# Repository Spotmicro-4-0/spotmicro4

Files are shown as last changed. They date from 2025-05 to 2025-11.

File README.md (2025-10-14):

# Spotmicro 4.0

All the 3D model SLT files are located here: [3D Models](3d-models/README.md)

## Setup Instructions

To get started with this repository, follow these steps:

1. **Use Visual Studio Code**: Clone the repository and open it in VS Code. Make sure to open the workspace file at the root of the repo (`spotmicroai.code-workspace`).

2. **Accept Recommended Plugins**: When prompted, accept the recommended extensions, which are primarily related to Python development.

3. **Create Environment**: Open the Command Palette (Ctrl+Shift+P) and select "Create Environment" to set up your Python environment.

4. **Install Dependencies**: Run the following command to install the development requirements:

   ```
   pip install -r requirements-dev.txt
   ```

- Configuring your controller
- [Joystick Documentation](docs/joystick.md)

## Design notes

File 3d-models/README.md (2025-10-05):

## 3D Models

Note: All parts were designed to be printed without the need for any support

### Assembly 1. Body
This is the central part of the bot, technically called the  tetrapod torso. It is basically the body of an animal without the 4 shoulders, limbs, head or buttock.

- It contains all the electronic components including the battery, except the LCD and the servos.
- Technically, the SBEC Cover and the Board Cover are optional. They can be skipped for now and printed at the end

|Assembly No|Assembly Name|Part|File Path|Count|Image||
|--|--|--|--|--|--|--|
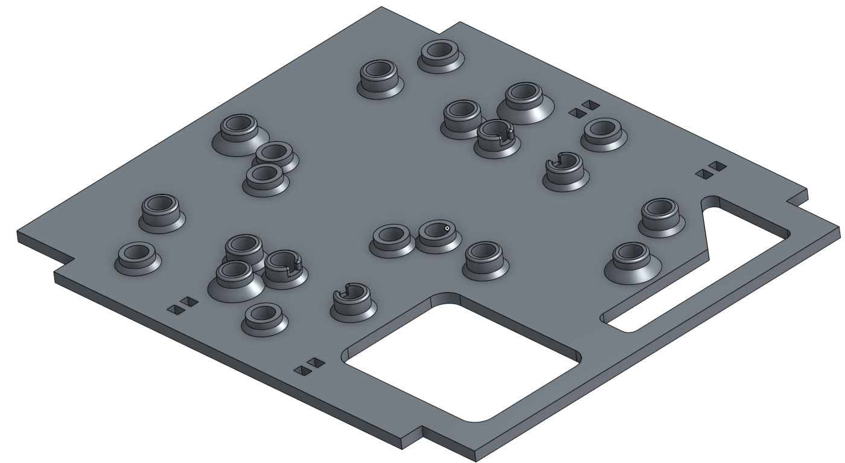
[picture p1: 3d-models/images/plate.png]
|1|Body|Plate|body/plate.stl|x1|||
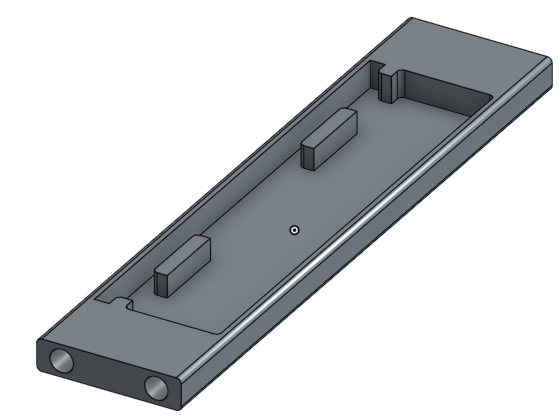
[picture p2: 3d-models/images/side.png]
|1|Body|Side|body/side.stl|x2|||
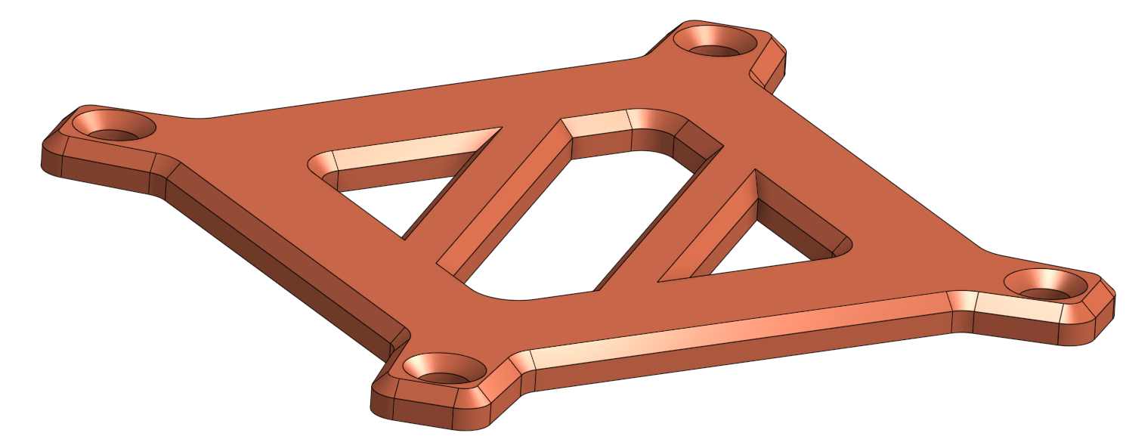
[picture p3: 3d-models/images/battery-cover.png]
|1|Body|Battery Cover|body/battery-cover.stl|x1||optional|
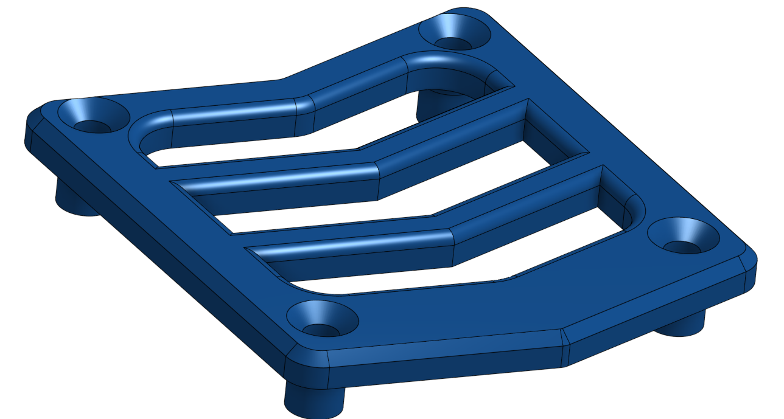
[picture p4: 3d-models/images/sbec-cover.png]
|1|Body|SBEC Cover|body/sbec-cover.stl|x1||optional|
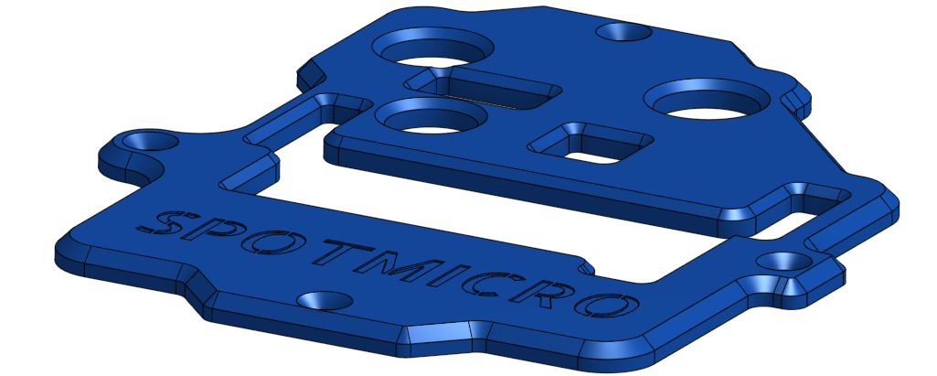
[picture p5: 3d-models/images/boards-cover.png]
|1|Body|Boards Cover|body/boards-cover.stl|x1||optional|

### Assembly 2. Front/Rear Shoulders

- This assembly is the shoulders cage that holds the Z-axis servos
- You will need two copies of this assembly
- Note that the limbs of the rear shoulders are reverse when compared to the front shoulders (left is right and right is left). More on that later

|Assembly No|Assembly Name|Part|File Path|Count|Image||
|--|--|--|--|--|--|--|
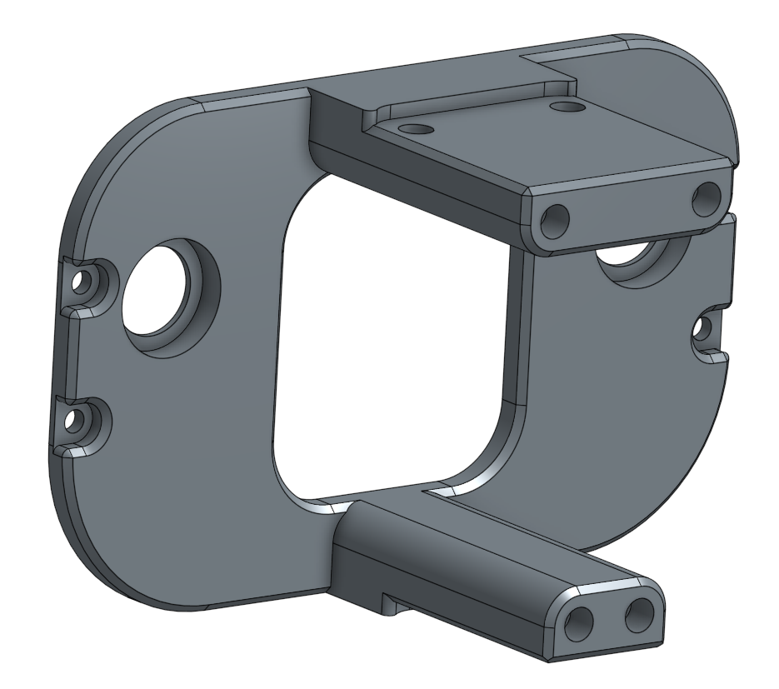
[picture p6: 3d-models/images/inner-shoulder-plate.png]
|2|Front/Rear Shoulders|Inner Shoulder Plate|shoulders/inner-plate/inner-shoulder-plate.stl|x2||
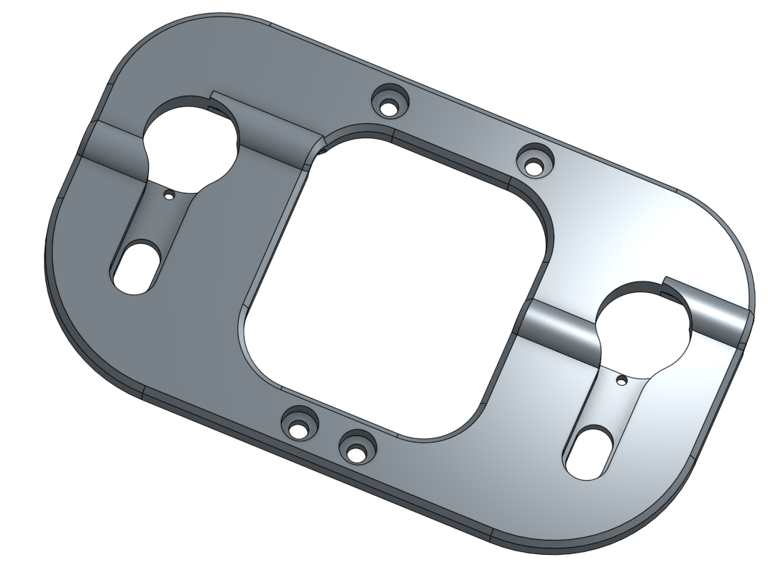
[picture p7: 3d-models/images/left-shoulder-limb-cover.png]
|2|Front/Rear Shoulders|Left Shoulder Limb Cover|shoulders/limb/left/left-shoulder-limb-cover.stl|x2||
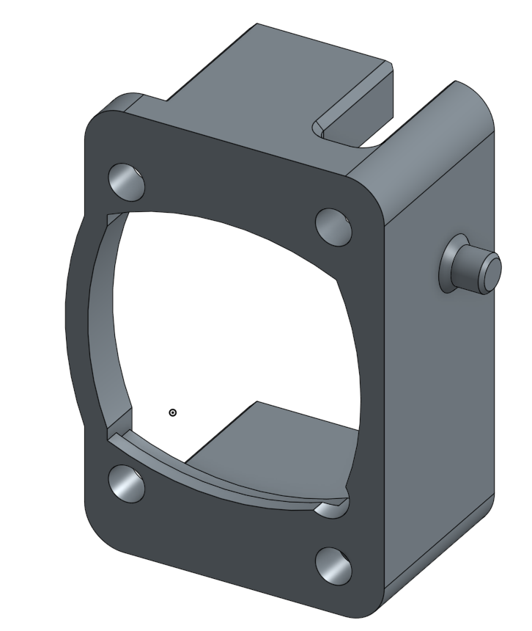
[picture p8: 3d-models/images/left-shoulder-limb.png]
|2|Front/Rear Shoulders|Left Shoulder Limb|shoulders/limb/left/left-shoulder-limb.stl|x2||
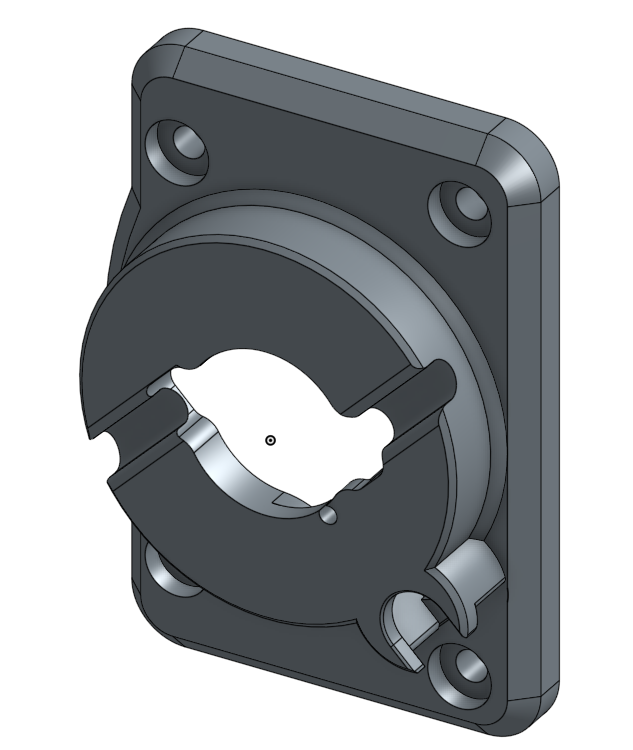
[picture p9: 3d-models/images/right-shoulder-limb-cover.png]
|2|Front/Rear Shoulders|Right Shoulder Limb Cover|shoulders/limb/right/right-shoulder-limb-cover.stl|x2||
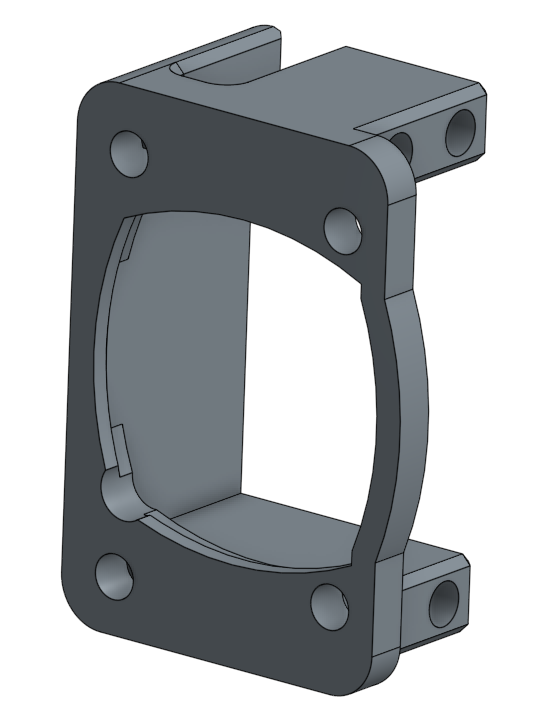
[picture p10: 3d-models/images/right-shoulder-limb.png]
|2|Front/Rear Shoulders|Right Shoulder Limb|shoulders/limb/right/right-shoulder-limb.stl|x2||
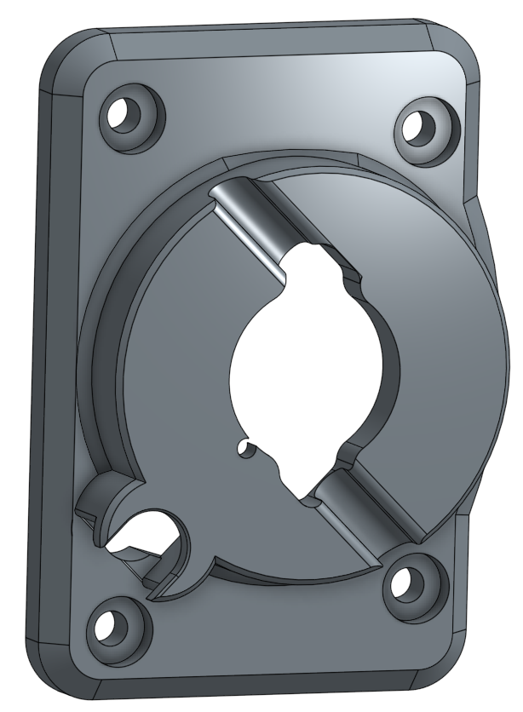
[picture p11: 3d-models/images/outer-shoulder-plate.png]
|2|Front/Rear Shoulders|Outer Shoulder Plate|shoulders/outer-plate/outer-shoulder-plate.stl|x2||

### Assembly 3. Left Leg
|Assembly No|Assembly Name|Part|File Path|Count|Image||
|--|--|--|--|--|--|--|
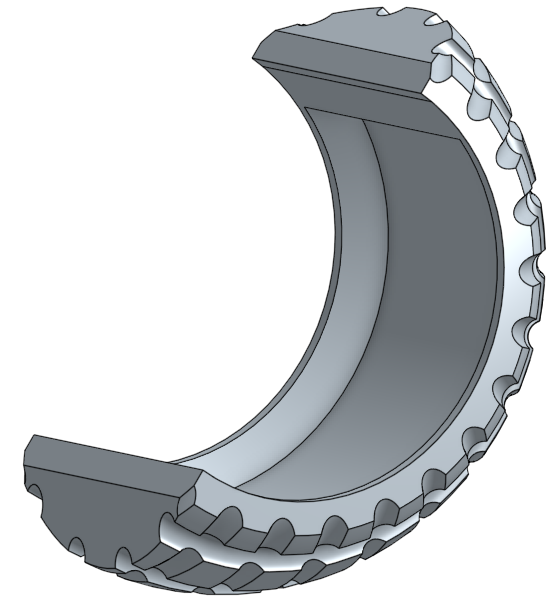
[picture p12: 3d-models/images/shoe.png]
|3|Left Leg|Shoe|legs/shoe.stl|x2||
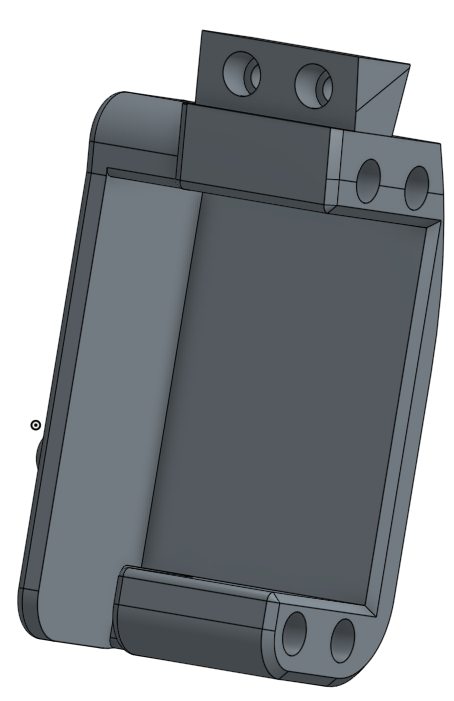
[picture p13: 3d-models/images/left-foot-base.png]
|3|Left Leg|Left Foot Base|legs/left/foot/left-foot-base.stl|x2||
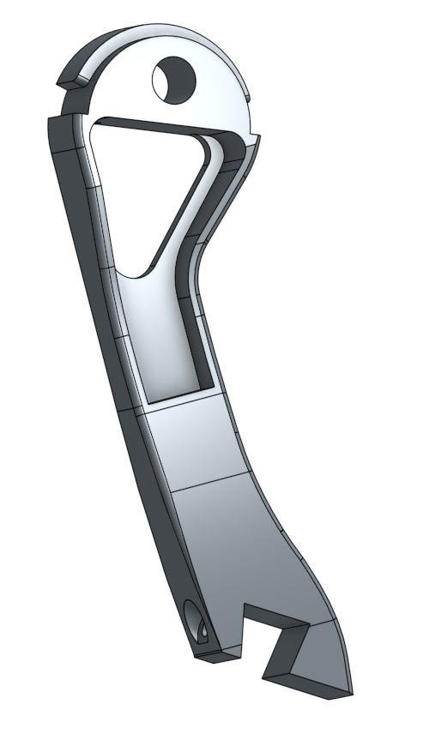
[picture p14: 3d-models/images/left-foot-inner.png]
|3|Left Leg|Left Foot Inner|legs/left/foot/left-foot-inner.stl|x2||
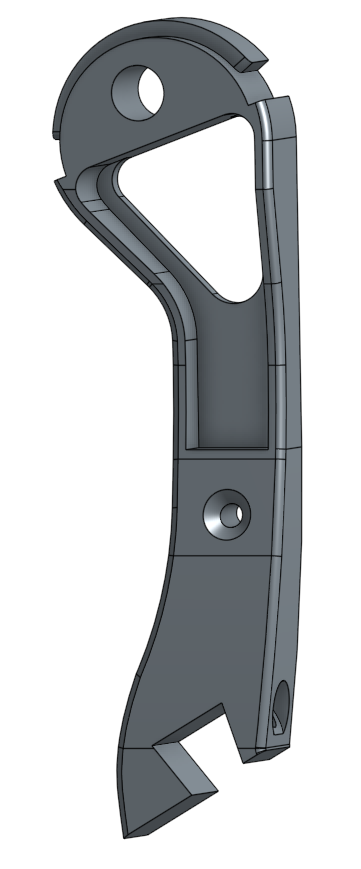
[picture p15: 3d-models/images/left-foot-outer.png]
|3|Left Leg|Left Foot Outer|legs/left/foot/left-foot-outer.stl|x2||
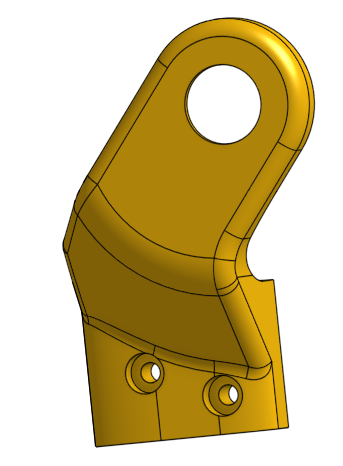
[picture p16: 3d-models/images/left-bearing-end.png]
|3|Left Leg|Bearing End|legs/left/leg/bearing-end.stl|x2||
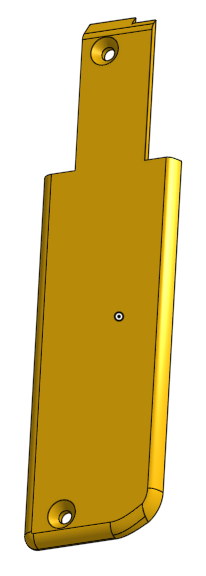
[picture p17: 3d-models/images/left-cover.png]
|3|Left Leg|Cover|legs/left/leg/cover.stl|x2||
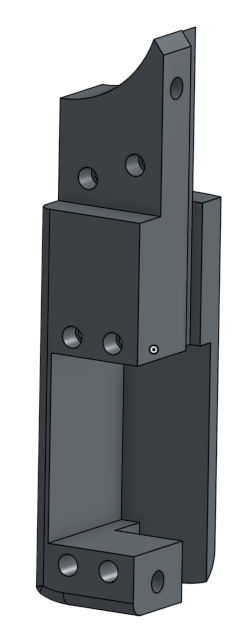
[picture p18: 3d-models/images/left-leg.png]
|3|Left Leg|Left Leg|legs/left/leg/left-leg.stl|x2||
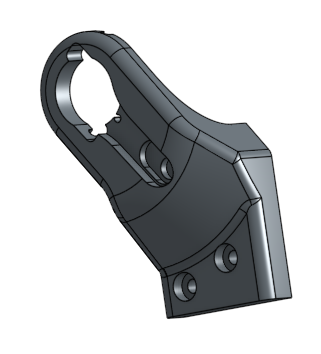
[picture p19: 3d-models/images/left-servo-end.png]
|3|Left Leg|Servo End|legs/left/leg/servo-end.stl|x2||

### Assembly 4. Right Leg
|Assembly No|Assembly Name|Part|File Path|Count|Image||
|--|--|--|--|--|--|--|
|4|Right Leg|Shoe|legs/shoe.stl|x2||
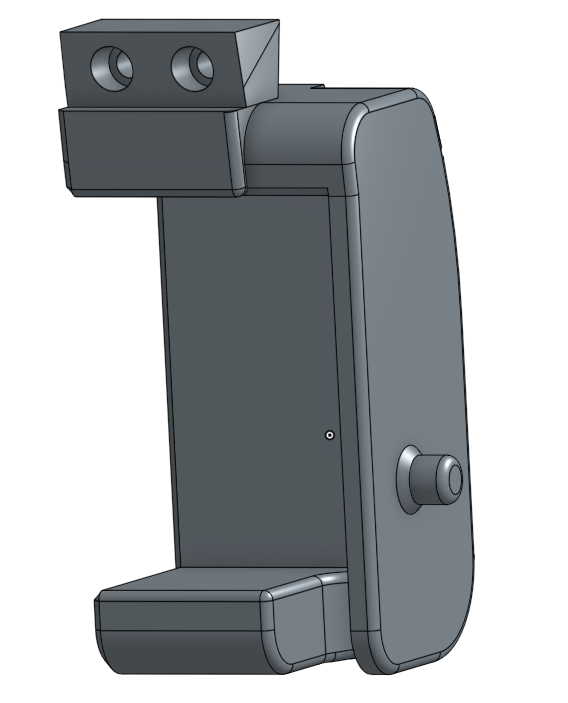
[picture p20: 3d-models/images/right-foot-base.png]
|4|Right Leg|Right Foot Base|legs/right/foot/right-foot-base.stl|x2||
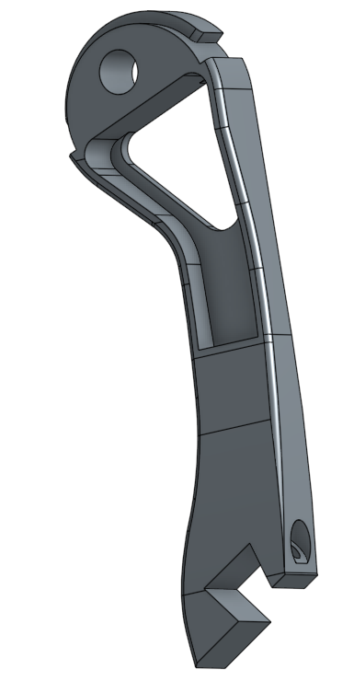
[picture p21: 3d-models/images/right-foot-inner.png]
|4|Right Leg|Right Foot Inner|legs/right/foot/right-foot-inner.stl|x2||
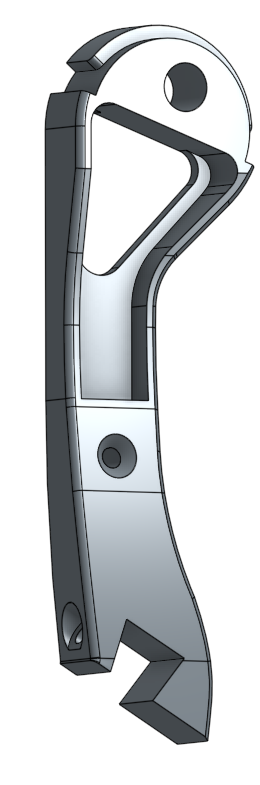
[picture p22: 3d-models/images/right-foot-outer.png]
|4|Right Leg|Right Foot Outer|legs/right/foot/right-foot-outer.stl|x2||
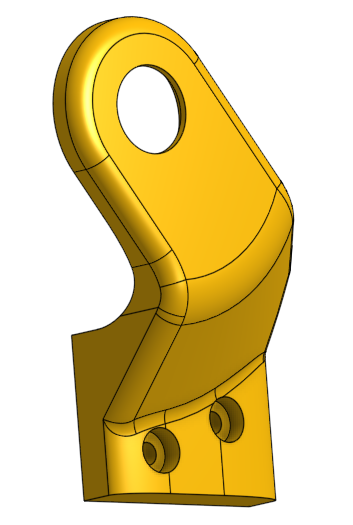
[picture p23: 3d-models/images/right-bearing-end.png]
|4|Right Leg|Bearing End|legs/right/leg/bearing-end.stl|x2||
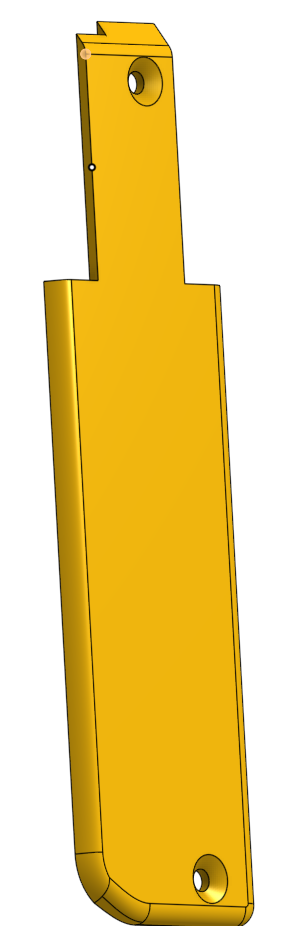
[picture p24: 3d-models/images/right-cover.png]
|4|Right Leg|Cover|legs/right/leg/cover.stl|x2||
|4|Right Leg|Right Leg|legs/right/leg/right-leg.stl|x2||
|4|Right Leg|Servo End|legs/right/leg/servo-end.stl|x2||

### Assembly 5. Top & Bottom Covers
Two very similar parts that wrap the body (the previous assembly). One cover goes on the top and the other on the bottom.

- The top cover has two openings, one for a power switch and another for accessing the battery charging connector
- The bottom cover has two optional parts that I call "offsets". They maybe needed if extra room is desired.

|Assembly No|Assembly Name|Part|File Path|Count|Image||
|--|--|--|--|--|--|--|
|5|Top/Bottom Covers|Bottom Panel|bottom/bottom-panel.stl|x1||
|5|Top/Bottom Covers|Edge Panel Connector|bottom/edge-panel-connector.stl|x4||
|5|Top/Bottom Covers|Left Side Panel|bottom/left-side-panel.stl|x2||
|5|Top/Bottom Covers|Offset|bottom/offset.stl|x2||
|5|Top/Bottom Covers|Right Side Panel|bottom/right-side-panel.stl|x2||
|5|Top/Bottom Covers|Charging Cover|top/charging-cover.stl|x1||
|5|Top/Bottom Covers|Top Cover with Opening|top/top-cover-with-opening.stl|x1||

### Assembly 6. Head
|Assembly No|Assembly Name|Part|File Path|Count|Image||
|--|--|--|--|--|--|--|
|6|Head|Connector|head/connector.stl|x1||
|6|Head|Face|head/face.stl|x1||
|6|Head|Middle|head/middle.stl|x1||
|6|Head|Nose|head/nose.stl|x1||

### Assembly 7. Rear
|Assembly No|Assembly Name|Part|File Path|Count|Image||
|--|--|--|--|--|--|--|
|7|Rear|Rear Cover|rear/rear-cover.stl|x2||

### Assembly 8. Stand

- Technically, this assembly is optional, but it is very difficult to calibrate and test the robot without it

|Assembly No|Assembly Name|Part|File Path|Count|Image||
|--|--|--|--|--|--|--|
|8|Stand|Base|stand/base-x-2.stl|x2||
|8|Stand|Cross Beam|stand/cross-beam-x-2.stl|x2||
|8|Stand|Foot|stand/foot-x-4.stl|x4||
|8|Stand|Fork|stand/fork-x-2.stl|x2||
|8|Stand|Stem|stand/stem-x-2.stl|x2||

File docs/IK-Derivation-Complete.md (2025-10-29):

# Inverse Kinematics Derivation for SpotMicro 3-DOF Leg with Shoulder Offset

Pure first-principles derivation. All formulas derived from scratch using only geometry and mathematics.

---

## 1. System Setup

### Physical Configuration
We have a 3-DOF leg with:
- **Joint 1 (Shoulder/Coxa)**: Located at origin p₁
- **Joint 2 (Hip/Femur base)**: Located at offset from p₁
- **Joint 3 (Knee/Tibia base)**: Connected to joint 2 via femur (L₁)
- **End effector (Foot)**: Connected to joint 3 via tibia (L₂)

### Coordinate Frame
- **X**: Forward/backward (positive backward)
- **Y**: Vertical (positive downward)
- **Z**: Lateral (positive rightward)

Origin p₁ is at the shoulder joint.

### Rigid Parameters
- **L₁** = 110 mm (femur/upper leg)
- **L₂** = 130 mm (tibia/lower leg)
- **Offset at rest**: When shoulder is at neutral (ω = 0), hip p₂ is at fixed position (28.5, 58.5, -10) relative to p₁

### Joint Angles
- **ω (omega)**: Shoulder rotation angle. Describes hip p₂ position around X-axis
- **θ (theta)**: Hip joint angle. Describes femur orientation in the plane perpendicular to shoulder axis
- **φ (phi)**: Knee joint angle. Internal angle between femur and tibia

---

## 2. Inverse Kinematics Derivation

### Problem Statement
Given a target foot position **t** = (X, Y, Z), find the joint angles (ω, θ, φ).

### Step 1: Derive ω (Shoulder Abduction/Adduction)

#### Physical Setup
The shoulder joint rotates around the X-axis. The hip joint p₂ is located at an offset from p₁. When the shoulder rotates by angle ω, the offset vector rotates in the YZ plane:

**At ω = 0°:**
$$p_2 = (x_{off}, y_{off}, z_{off}) = (28.5, 58.5, -10)$$

**After rotation by ω around X-axis:**
$$p_{2y} = y_{off}\cos(ω) - z_{off}\sin(ω)$$
$$p_{2z} = y_{off}\sin(ω) + z_{off}\cos(ω)$$

#### Deriving the Constraint
The key constraint is that the foot's Z-coordinate must equal the rotated offset's Z-component:
$$Z = y_{off}\sin(ω) + z_{off}\cos(ω)$$

#### Rewriting with Trigonometric Identity
We can rewrite the right-hand side using the sum formula:
$$Z = \sqrt{y_{off}^2 + z_{off}^2} \left[\frac{y_{off}}{\sqrt{y_{off}^2 + z_{off}^2}}\sin(ω) + \frac{z_{off}}{\sqrt{y_{off}^2 + z_{off}^2}}\cos(ω)\right]$$

Let $\sin(\delta) = \frac{z_{off}}{R}$ and $\cos(\delta) = \frac{y_{off}}{R}$:
$$Z = R[\cos(\delta)\sin(ω) + \sin(\delta)\cos(ω)]$$
$$Z = R\sin(ω + \delta)$$

#### Solving for ω
$$\sin(ω + \delta) = \frac{Z}{R}$$
$$ω + \delta = \arcsin\left(\frac{Z}{R}\right)$$

**Therefore:**
$$\boxed{ω = \arcsin\left(\frac{Z}{R}\right) - \delta}$$

#### Reachability Constraint
$$|Z| \le R \quad \Rightarrow \quad |Z| \le 59.35 \text{ mm}$$

---

### Step 2: Compute p₂ (Hip Position After Shoulder Rotation)

Once ω is determined, the hip joint position is:

$$\boxed{p_{2x} = x_{off} = 28.5 \text{ mm}}$$

$$\boxed{p_{2y} = y_{off}\cos(ω) - z_{off}\sin(ω) = 58.5\cos(ω) + 10\sin(ω)}$$

$$\boxed{p_{2z} = Z}$$

(The Z-coordinate equals the target Z by construction.)

---

### Step 3: Reduce to 2D Planar Problem

#### Project to XY Plane
The leg's remaining two joints (hip and knee) operate in the XY plane. We compute the relative position of the target foot from the hip joint:

$$\boxed{\Delta x = X - p_{2x} = X - 28.5}$$

$$\boxed{\Delta y = Y - p_{2y}}$$

#### Hip-to-Foot Distance
$$\boxed{d = \sqrt{(\Delta x)^2 + (\Delta y)^2}}$$

#### Reachability Constraint (2D Triangle Inequality)
For the two-link chain (L₁ and L₂) to reach distance d:
$$|L_1 - L_2| \le d \le L_1 + L_2$$
$$20 \text{ mm} \le d \le 240 \text{ mm}$$

---

### Step 4: Solve φ (Knee Internal Angle)

#### Law of Cosines
The hip joint p₂, end of femur p₃, and foot target t form a triangle with known side lengths L₁, L₂, and d.

Using the law of cosines:
$$d^2 = L_1^2 + L_2^2 - 2L_1L_2\cos(φ)$$

#### Solving for φ
$$\cos(φ) = \frac{L_1^2 + L_2^2 - d^2}{2L_1L_2}$$

$$\boxed{φ = \arccos\left(\frac{L_1^2 + L_2^2 - d^2}{2L_1L_2}\right)}$$

#### Numerical Robustness
Clamp the arccos argument to [-1, 1] to prevent numerical errors:
$$\cos(φ) = \max(-1, \min(1, \cos(φ)))$$

#### Special Cases
- When $φ = 0°$ (π radians): leg is fully extended
- When $φ = 180°$ (0 radians): leg is fully folded back

---

### Step 5: Solve θ (Hip Pitch Angle)

#### Decomposition into Auxiliary Angles
The hip angle is decomposed into two angles that must be combined:

**Angle α**: Direction from hip p₂ to foot t in the XY plane
$$\boxed{\alpha = \arctan2(\Delta y, \Delta x)}$$

**Angle β**: Angle between the femur (L₁) and the line from hip to foot
Using the law of cosines on the same triangle:
$$L_2^2 = L_1^2 + d^2 - 2L_1 d\cos(β)$$

$$\cos(β) = \frac{L_1^2 + d^2 - L_2^2}{2L_1 d}$$

$$\boxed{\beta = \arccos\left(\frac{L_1^2 + d^2 - L_2^2}{2L_1 d}\right)}$$

#### Numerical Robustness
Clamp the arccos argument:
$$\cos(β) = \max(-1, \min(1, \cos(β)))$$

#### Hip Angle (Knee-Down Configuration)
The femur angle is oriented at angle α, and β is the angle between the femur and the hip-to-foot line. In the "knee-down" (typical) configuration:

$$\boxed{\theta = \alpha - \beta}$$

#### Alternative (Knee-Up Configuration)
For an inverted leg geometry:
$$\theta = \alpha + \beta$$

---

## 3. Complete Algorithm

### Input
Target foot position: $(X, Y, Z)$ in mm

### Output
Joint angles: $(ω, θ, φ)$ in radians

### Algorithm Steps

```
1. Compute shoulder angle:
   IF |Z| > R:
      RETURN ERROR: "Z out of reach"
   END IF
   ω = arcsin(Z/R) - δ

2. Compute hip position:
   p₂ₓ = xₒff
   p₂ᵧ = yₒff·cos(ω) - zₒff·sin(ω)

3. Project to 2D plane:
   Δx = X - p₂ₓ
   Δy = Y - p₂ᵧ
   d = √(Δx² + Δy²)

4. Check 2D reachability:
   IF d < |L₁ - L₂| OR d > L₁ + L₂:
      RETURN ERROR: "Target distance unreachable"
   END IF

5. Compute knee angle:
   cos(φ) = clamp((L₁² + L₂² - d²)/(2·L₁·L₂), -1, 1)
   φ = arccos(cos(φ))

6. Compute hip angle:
   α = atan2(Δy, Δx)
   cos(β) = clamp((L₁² + d² - L₂²)/(2·L₁·d), -1, 1)
   β = arccos(cos(β))
   θ = α - β  (knee-down) or α + β (knee-up)

7. RETURN (ω, θ, φ)
```

---

## 4. Numerical Implementation

### Constants
```
L₁ = 110 mm
L₂ = 130 mm
xₒff = 28.5 mm
yₒff = 58.5 mm
zₒff = -10 mm
R = 59.35 mm
δ ≈ -0.1693 rad
```

### Pseudo-code with Clamping

```python
def inverse_kinematics(X, Y, Z):
    # Step 1: Shoulder angle
    if abs(Z) > R:
        raise ValueError(f"Z={Z} unreachable (max: ±{R})")
    omega = asin(Z/R) - delta
    
    # Step 2: Hip position
    p2x = x_off
    p2y = y_off*cos(omega) - z_off*sin(omega)
    
    # Step 3: 2D projection
    dx = X - p2x
    dy = Y - p2y
    d = sqrt(dx² + dy²)
    
    # Step 4: Check reachability
    if d < abs(L1 - L2) or d > L1 + L2:
        raise ValueError(f"d={d} unreachable")
    
    # Step 5: Knee angle
    cos_phi = clamp((L1² + L2² - d²)/(2*L1*L2), -1, 1)
    phi = acos(cos_phi)
    
    # Step 6: Hip angle
    alpha = atan2(dy, dx)
    cos_beta = clamp((L1² + d² - L2²)/(2*L1*d), -1, 1)
    beta = acos(cos_beta)
    theta = alpha - beta
    
    return omega, theta, phi
```

---

## 5. Validation & Examples

### Example 1: Foot Straight Down
**Input**: X=28.5, Y=170, Z=0

Expected: ω ≈ δ (since arcsin(0) = 0)

**Calculation**:
- ω = arcsin(0) - (-0.1693) = 0.1693 rad ≈ 9.70°
- p₂y = 58.5·cos(0.1693) + 10·sin(0.1693) ≈ 58.36 mm
- d ≈ √(0² + (170-58.36)²) ≈ 111.64 mm

### Example 2: Foot Forward and Down
**Input**: X=60, Y=143, Z=50

Expected: ω > δ (positive Z rotates shoulder to the right)

**Calculation**:
- ω = arcsin(50/59.35) - (-0.1693) ≈ 1.017 rad ≈ 58.29°
- p₂y = 58.5·cos(1.017) + 10·sin(1.017) ≈ 38.47 mm
- d ≈ √((60-28.5)² + (143-38.47)²) ≈ 109.47 mm

---

## 6. Reachability Envelope

The workspace is bounded by:

1. **Z-reach** (shoulder abduction/adduction):
   $$-59.35 \text{ mm} \le Z \le 59.35 \text{ mm}$$

2. **XY-reach** (hip and knee in 2D plane):
   $$20 \text{ mm} \le d \le 240 \text{ mm}$$
   where $d = \sqrt{(X-28.5)^2 + (Y-p_{2y})^2}$

3. **Combined constraint**: The workspace is a 3D region bounded by these limits.

---

## 7. Notes on Implementation

- **Use radians** internally; convert to degrees for display if needed
- **Numerical robustness**: Always clamp arccos arguments to [-1, 1]
- **Branch selection**: The formulas assume the "knee-down" configuration; use $\theta = \alpha + \beta$ for alternative geometry
- **Error handling**: Check both Z-reach and 2D distance reachability before computing angles
- **Singularities**: φ approaches 0 or π at the boundaries of reach; behavior at singularities may cause numerical issues

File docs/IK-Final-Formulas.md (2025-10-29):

# SpotMicro Inverse Kinematics - Final Mathematical Formulas

**As implemented and tested - exact formulas without calibration fudging**

---

## System Parameters

```
L₁ = 110 mm    (femur length)
L₂ = 130 mm    (tibia length)
x_off = 28.55 mm    (X offset of hip from shoulder)
y_off = 10.5 mm     (Y offset of hip at natural position)
z_off = 58.49 mm    (Z offset of hip at natural position)
```

## Joint Angle Convention

- **ω = 90°**: Normal standing position (leg pointing straight down)
- **ω = 180°**: Leg pointing straight sideways
- **ω = 0°**: Leg pointing inward (adducted)
- **θ = 0°**: Femur pointing straight down
- **θ = 90°**: Femur pointing straight backward (along X-axis)
- **φ**: Internal knee angle between femur and tibia

---

## Mathematical Formulas

### Step 1: Solve ω (Shoulder Angle)

**Constraint equation:**
$$Z = -y_{off} \cdot \cos(ω) + z_{off} \cdot \sin(ω)$$

**Rewritten as:**
$$Z = R \cdot \sin(ω + φ)$$

where:
$$R = \sqrt{y_{off}^2 + z_{off}^2}$$
$$φ = \arctan2(-y_{off}, z_{off})$$

**Solution:**
$$ω = \arcsin\left(\frac{Z}{R}\right) - φ$$

**Reachability constraint:**
$$|Z| \leq R$$

### Step 2: Compute Hip Position p₂

$$p_{2x} = x_{off}$$
$$p_{2y} = y_{off} \cdot \sin(ω) + z_{off} \cdot \cos(ω)$$
$$p_{2z} = Z \quad \text{(by construction)}$$

### Step 3: Project to 2D Problem

$$\Delta x = X - p_{2x}$$
$$\Delta y = Y - p_{2y}$$
$$d = \sqrt{(\Delta x)^2 + (\Delta y)^2}$$

**Reachability constraint:**
$$|L_1 - L_2| \leq d \leq L_1 + L_2$$

### Step 4: Solve φ (Knee Angle)

**Law of cosines:**
$$\cos(φ) = \frac{L_1^2 + L_2^2 - d^2}{2L_1L_2}$$

**Solution:**
$$φ = \arccos\left(\text{clamp}\left(\frac{L_1^2 + L_2^2 - d^2}{2L_1L_2}, -1, 1\right)\right)$$

### Step 5: Solve θ (Hip Angle)

**Auxiliary angles:**
$$α = \arctan2(\Delta y, \Delta x)$$
$$β = \arccos\left(\text{clamp}\left(\frac{L_1^2 + d^2 - L_2^2}{2L_1d}, -1, 1\right)\right)$$

**Solution (as currently implemented):**
$$θ = \frac{π}{2} - α + β$$

---

## Summary Algorithm

```python
def inverse_kinematics(X, Y, Z):
    # Step 1: Shoulder angle
    R = sqrt(y_off² + z_off²)
    phi = atan2(-y_off, z_off)
    omega = asin(Z/R) - phi
    
    # Step 2: Hip position
    p2x = x_off
    p2y = y_off * sin(omega) + z_off * cos(omega)
    
    # Step 3: 2D projection
    dx = X - p2x
    dy = Y - p2y
    d = sqrt(dx² + dy²)
    
    # Step 4: Knee angle
    phi = acos(clamp((L1² + L2² - d²)/(2*L1*L2), -1, 1))
    
    # Step 5: Hip angle
    alpha = atan2(dy, dx)
    beta = acos(clamp((L1² + d² - L2²)/(2*L1*d), -1, 1))
    theta = π/2 - alpha + beta
    
    return (omega, theta, phi)
```

---

## Notes

- **The θ formula produces values ~6° lower than expected measurements**
- **The 0.105 radian (~6°) offset in the code is a calibration fudge, not a mathematical solution**
- **The underlying geometric relationship for θ may need reconsideration**
- **All other angles (ω and φ) match measurements accurately**

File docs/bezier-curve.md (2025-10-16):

# Bézier Curve Foot Trajectory Generator (SpotMicro4)

## Overview
This script replaces the discrete 6-point keyframe “box” walking cycle for a single foot with a **smooth Bézier curve** trajectory.  
Each keyframe defines a 3D coordinate `(X, Y, Z)` in millimeters:
- **X** → forward/backward  
- **Y** → up/down (vertical)  
- **Z** → inward/outward (toward/away from the robot center)

By interpolating these six positions using a Bézier curve, we generate a continuous, smooth path that the robot’s foot can follow during a walking step, reducing mechanical jerk and improving realism.

The Y-axis is plotted **vertically**, and inverted so that positive Y values correspond to **downward movement**, matching the robot’s coordinate convention.

---

## Script: `bezier.py`

```python
import numpy as np
import matplotlib.pyplot as plt
import math

# Your 6 keyframes (in mm)
points = np.array([
    [-60, 150, 40],
    [-60, 80, 40],
    [60, 80, 40],
    [60, 150, 40],
    [35, 150, 40],
    [-35, 150, 40],
])

def bezier_curve(points, num=200):
    n = len(points) - 1
    t = np.linspace(0, 1, num)
    curve = np.zeros((num, 3))
    for i in range(n + 1):
        binomial = math.comb(n, i)
        curve += (
            binomial * ((1 - t) ** (n - i)) * (t ** i)
        )[:, None] * points[i]
    return curve

curve = bezier_curve(points)

# Plot with Y as vertical and inverted
fig = plt.figure()
ax = fig.add_subplot(projection='3d')

# Swap Y/Z for visualization so Y is vertical
ax.plot(points[:, 0], points[:, 2], points[:, 1], 'ro--', label='Keyframes')
ax.plot(curve[:, 0], curve[:, 2], curve[:, 1], 'b-', label='Bezier Curve')

ax.set_xlabel('X (forward/backward)')
ax.set_ylabel('Z (outward/inward)')
ax.set_zlabel('Y (up/down)')
ax.invert_zaxis()  # invert Y axis (vertical)
ax.legend()
plt.tight_layout()
plt.savefig("bezier_curve.png", dpi=200)
print("Saved to bezier_curve.png with Y axis inverted (downward positive)")
```

## Output

Running the script:

```bash
python3 src/bezier.py
```

produces: `bezier_curve.png`

This PNG visualizes:

- The original 6 red keyframes connected by dashed lines
- The smooth blue Bézier curve interpolating the same spatial path
- The Y-axis plotted vertically and inverted to reflect the robot's coordinate frame.

Bezier Curve Visualization

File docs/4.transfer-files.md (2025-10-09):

- Enable i2c driver
sudo nano /boot/firmware/config.txt
dtparam=i2c_arm=on

- create a spotmicro folder
cd ~/spotmicroai || exit

- python3 -m venv venv --clear
- source venv/bin/activate

- install pip
curl https://bootstrap.pypa.io/get-pip.py | python
- install packages
sudo apt install python3-rpi.gpio

python3 -m pip install --upgrade pip setuptools jmespath throttle adafruit-circuitpython-motor adafruit-circuitpython-pca9685 inputs smbus RPi.GPIO pick

- copy files over to the rpi
- copy json

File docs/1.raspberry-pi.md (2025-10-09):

# Raspberry Pi Zero 2 W Setup Guide (Bookworm Lite)

This guide explains how to prepare a **microSD card** for your Raspberry Pi Zero 2 W using the **Raspberry Pi Imager**. It walks through selecting the correct image, configuring Wi-Fi, setting up credentials, and assigning a hostname.

---

## 1. Requirements

Before you begin, make sure you have:

* A **Raspberry Pi Zero 2 W** board
* A **microSD card** (8 GB minimum, 16 GB recommended)
* A **microSD card reader** for your computer
* A stable **Wi-Fi network**
* A computer running **Windows, macOS, or Linux**
* The latest **Raspberry Pi Imager** installed ([Download here](https://www.raspberrypi.com/software))

---

## 2. Launch Raspberry Pi Imager

1. Open the **Raspberry Pi Imager** application on your computer.
2. Click **"Choose Device"** and select **Raspberry Pi Zero 2 W**.

---

## 3. Choose the Operating System

1. Click **"Choose OS"**.
2. Navigate to:

   ```
   Raspberry Pi OS (other) → Raspberry Pi OS Lite (64-bit)
   ```

   This version (Bookworm Lite) is **command-line only** and ideal for robots or headless projects.

---

## 4. Select the Storage Device

1. Click **"Choose Storage"**.
2. Select your **microSD card** from the list. Make sure you choose the correct drive — this will erase all existing data.

---

## 5. Configure Advanced Settings

Click the small **gear icon ⚙️** or press **Ctrl + Shift + X** to open the **Advanced Options** menu.

Enable and configure the following:

### a. Set Hostname

```
spotmicroai
```

(You can choose another if desired, but `spotmicroai` is recommended.)

### b. Enable SSH

* Check **Enable SSH**
* Select **Use password authentication**

### c. Set Username and Password

Use simple credentials for first setup:

```
Username: pi
Password: raspberry
```

(You can change these later using the `passwd` command.)

### d. Configure Wi-Fi

Enter your Wi-Fi credentials:

```
SSID: <your_network_name>
Password: <your_network_password>
Country: US
```

Ensure the Wi-Fi name and password are typed exactly as they appear on your network.

### e. Set Locale Options

Optionally, adjust **Time Zone** and **Keyboard Layout** to match your region.

---

## 6. Save and Write the Image

1. Click **Save** to close the Advanced Options.
2. Click **Write** to begin flashing the SD card.
3. Wait for the process to complete — this may take a few minutes.
4. When finished, remove the SD card safely from your computer.

---

## 7. Boot the Raspberry Pi

1. Insert the flashed microSD card into the **Raspberry Pi Zero 2 W**.
2. Connect power via the **micro-USB port**.
3. Wait for it to boot (usually 30–60 seconds).

If configured correctly, your Pi will:

* Automatically connect to your Wi-Fi
* Be reachable via SSH at the hostname you set

You can verify connectivity by running from another computer on the same network:

```bash
ping spotmicroai.local
```

Or SSH into it directly:

```bash
ssh pi@spotmicroai.local
```

(Use the password you configured earlier.)

---

## 8. Optional: Verify System Details

Once connected, check:

```bash
hostnamectl
```

This confirms your hostname, OS version (Bookworm Lite), and architecture.

---

## 9. Next Steps

* Update packages: `sudo apt update && sudo apt upgrade -y`
* Install additional tools if needed (`git`, `python3`, `pip`, etc.)
* Begin deploying your robot or automation code.

Your Raspberry Pi Zero 2 W is now ready for headless operation.

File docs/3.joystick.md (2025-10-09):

# Game Controller Setup Guide for Raspberry Pi

This guide explains how to pair and test an **Xbox or PlayStation controller** wirelessly via Bluetooth on a Raspberry Pi.
It assumes you are using **Raspberry Pi OS Bookworm** or **Bullseye**.

---

## Prerequisites

Ensure your system is up to date. On most Bookworm installations, Bluetooth support is already included. The only extra package needed is `joystick` to use the testing tool.

```bash
sudo apt update
sudo apt upgrade -y
sudo apt install -y joystick
```

Verify that Bluetooth is active:

```bash
systemctl status bluetooth
```

If you see `active (running)`, you are ready.

---

## Supported Controllers

| Controller | Works via Bluetooth | Notes |
| --- | --- | --- |
| Xbox One S / Series X | Yes | Requires Bluetooth 4.0+; may need `xpadneo` driver for full rumble and battery support |
| PlayStation DualShock 4 | Yes | Fully supported by built-in Linux driver `hid-sony` |
| PlayStation DualSense (PS5) | Yes | Supported by `hid-playstation` driver in kernel 5.12+ |

---

## Pairing the Controller

### 1. Start Bluetooth services

```bash
sudo systemctl enable bluetooth
sudo systemctl start bluetooth
```

### 2. Enter the Bluetooth shell

```bash
bluetoothctl
```

Then run:

```text
power on
agent on
default-agent
scan on
```

---

### 3. Put the controller in pairing mode

* **Xbox controller:** Hold the **Pair** button (on top near the USB port) until the Xbox logo blinks rapidly.
* **PlayStation controller:** Hold **Share + PS** buttons together until the light bar flashes quickly.

---

### 4. Wait for detection

When the controller is found, you will see output like:

```
[NEW] Device DC:0C:2D:AB:1E:5A Xbox Wireless Controller
```

or

```
[NEW] Device 04:5D:4B:8A:BB:9E Wireless Controller
```

---

### 5. Pair and connect

Replace <MAC> with the detected Bluetooth address:

```text
pair <MAC>
trust <MAC>
connect <MAC>
```

Once connected, the controller light becomes solid.

---

### 6. Verify input device

Exit `bluetoothctl` and check:

```bash
ls /dev/input/
```

You should see something like:

```
js0
```

Test it:

```bash
jstest /dev/input/js0
```

Move the sticks or press buttons to confirm input is detected.

---

## Troubleshooting

### Controller not detected

Restart Bluetooth services:

```bash
sudo systemctl restart bluetooth
```

If still not listed, unpair and try again:

```bash
bluetoothctl
remove <MAC>
```

### Controller disconnects automatically

Controllers enter sleep mode when idle. Press the main button (Xbox logo or PS button) to reconnect.

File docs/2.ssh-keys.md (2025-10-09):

# Secure SSH Key Setup for Raspberry Pi

This guide explains how to configure passwordless SSH access to your Raspberry Pi using public and private key authentication. It applies to Raspberry Pi OS Bookworm (Lite or Desktop) and works from Linux, macOS, or Windows (including WSL or PowerShell).

---

## 1. Prerequisites

You should already have:

* Your Raspberry Pi powered on and connected to Wi-Fi or Ethernet
* SSH enabled on the Pi

  * If not, run `sudo raspi-config`, go to Interface Options > SSH > Enable
* The hostname or IP address of your Pi (for example, `spotmicroai.local`)

---

## 2. Check for Existing SSH Keys (on Your Computer)

Open a terminal on your local computer (not the Pi):

```bash
ls ~/.ssh
```

If you see files such as `id_rsa` and `id_rsa.pub` or `id_ed25519` and `id_ed25519.pub`, you already have a key pair and can skip to Step 4.

If not, continue.

---

## 3. Generate a New SSH Key Pair

Run the following command on your local computer:

```bash
ssh-keygen -t ed25519 -C "your_email@example.com"
```

Explanation:

* `-t ed25519` creates a modern, secure key type (recommended over RSA)
* `-C` adds an optional comment to help identify the key later

Press Enter to accept the default file location (`~/.ssh/id_ed25519`) and optionally set a passphrase for extra security.

---

## 4. Copy Your Public Key to the Raspberry Pi

Use one of the following methods.

### Option A: Using ssh-copy-id (recommended)

```bash
ssh-copy-id pi@spotmicroai.local
```

Replace `pi@spotmicroai.local` with your Pi's username and hostname or IP address. You will be asked for your Pi's password one last time. This command automatically adds your key to `~/.ssh/authorized_keys` on the Pi.

### Option B: Manual Copy

If `ssh-copy-id` is not available, you can copy the key manually:

1. Display your public key:

   ```bash
   cat ~/.ssh/id_ed25519.pub
   ```
2. Copy the output string.
3. On the Pi, connect via password SSH:

   ```bash
   ssh pi@spotmicroai.local
   ```
4. On the Pi, create or edit the file:

   ```bash
   mkdir -p ~/.ssh
   nano ~/.ssh/authorized_keys
   ```
5. Paste the public key into the file, save, and exit.
6. Set the correct permissions:

   ```bash
   chmod 700 ~/.ssh
   chmod 600 ~/.ssh/authorized_keys
   ```

---

## 5. Test the Connection

On your local computer, run:

```bash
ssh pi@spotmicroai.local
```

If setup was successful, you should connect without being asked for a password.

---

## 6. Troubleshooting

If you are still prompted for a password:

* Ensure SSH is enabled on the Pi: `sudo systemctl status ssh`
* Check that your key was copied correctly to `~/.ssh/authorized_keys`
* Verify file permissions are correct (as listed above)
* Make sure you are connecting as the same username for which the key was installed

---

## 7. Optional: Use a Custom Key Path

If your key is stored in a custom file, specify it with:

```bash
ssh -i ~/.ssh/custom_key pi@spotmicroai.local
```

You can also define this permanently in an SSH config file:

```bash
nano ~/.ssh/config
```

Example configuration:

```text
Host spotmicroai
    HostName spotmicroai.local
    User pi
    IdentityFile ~/.ssh/id_ed25519
```

Now you can simply connect using:

```bash
ssh spotmicroai
```

Your Raspberry Pi is now configured for secure, passwo

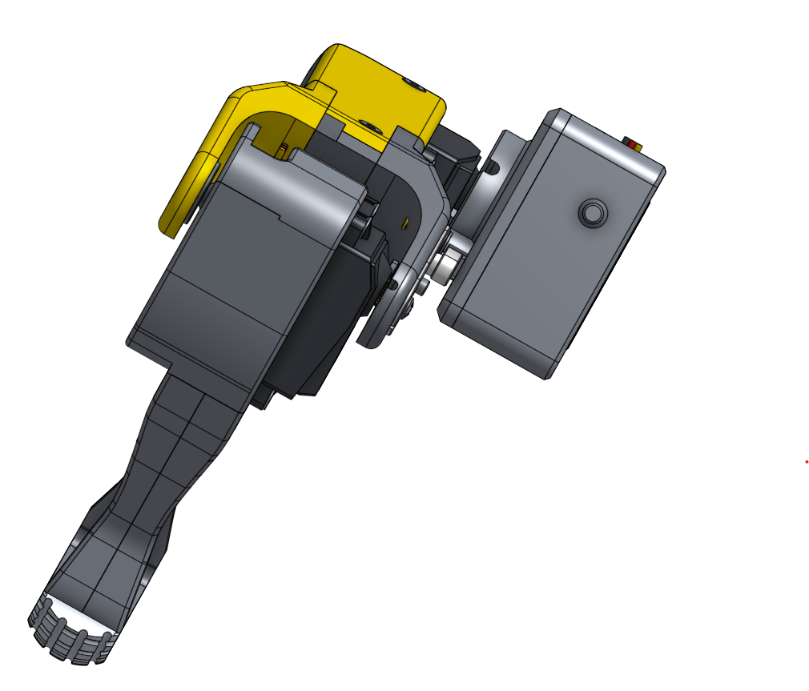
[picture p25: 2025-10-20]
docs/images/inverse-kinematics-rear.png

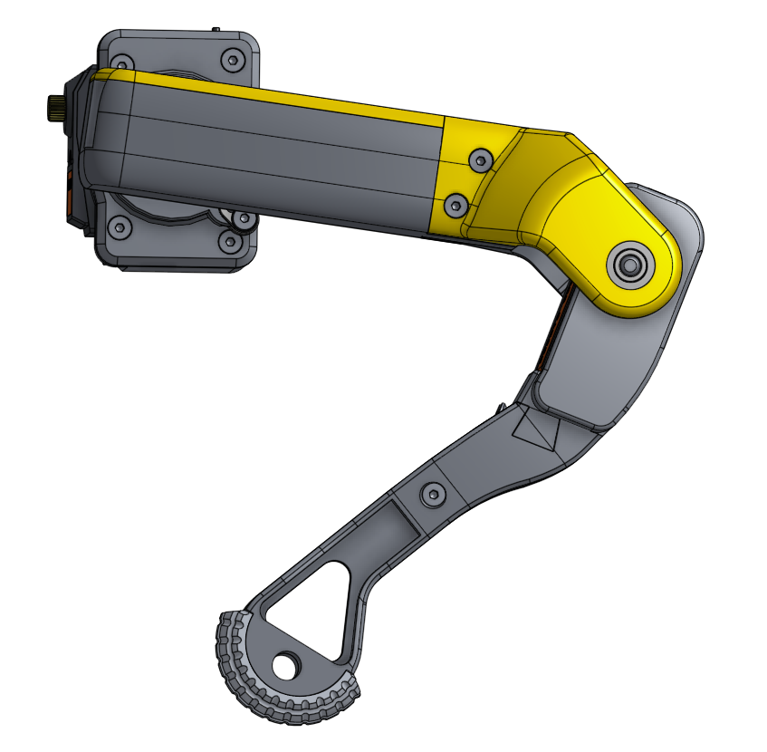
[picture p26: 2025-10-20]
docs/images/inverse-kinematics-side.png

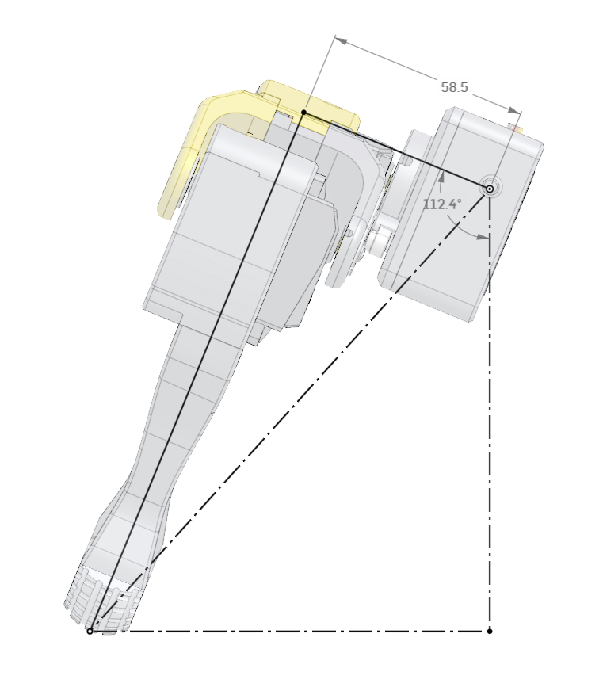
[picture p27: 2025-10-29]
docs/images/image.png

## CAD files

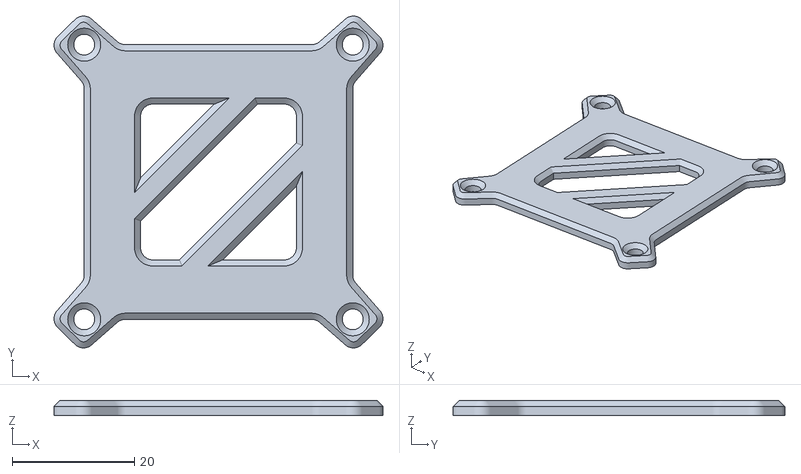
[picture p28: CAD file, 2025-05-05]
3d-models/body/battery-cover.stl
53.9 x 54.4 x 2.50

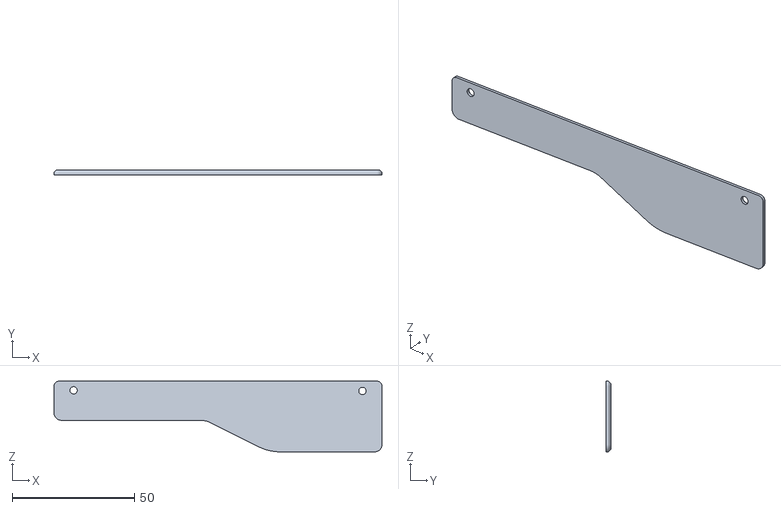
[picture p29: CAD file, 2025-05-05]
3d-models/bottom/right-side-panel.stl
134.0 x 2.00 x 28.9

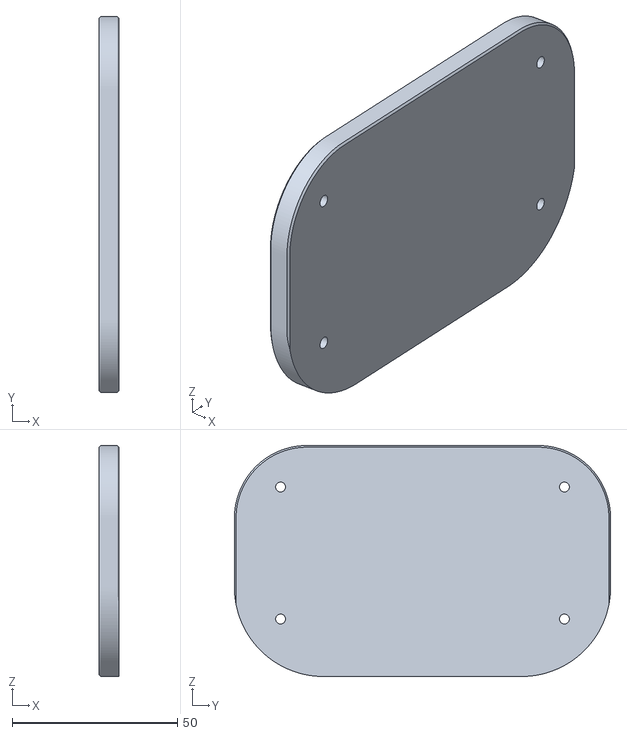
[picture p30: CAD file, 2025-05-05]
3d-models/head/middle.stl
6.00 x 114.0 x 70.0

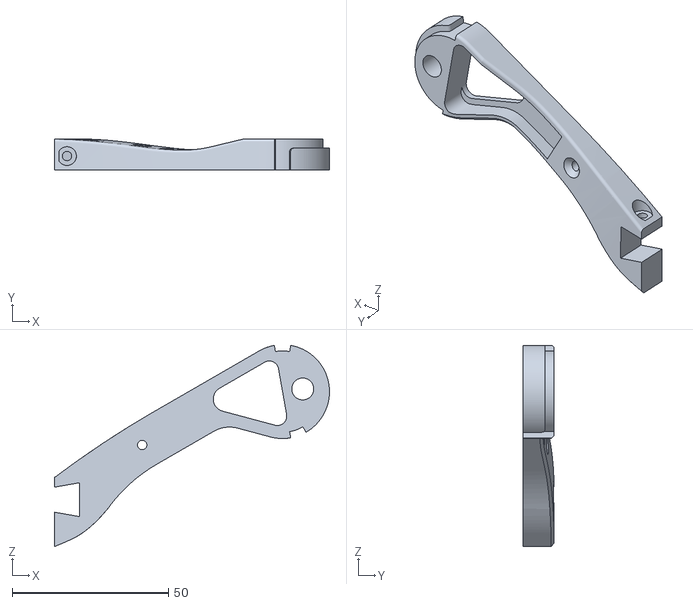
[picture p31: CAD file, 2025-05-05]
3d-models/legs/left/foot/left-foot-outer.stl
87.9 x 10.0 x 64.3

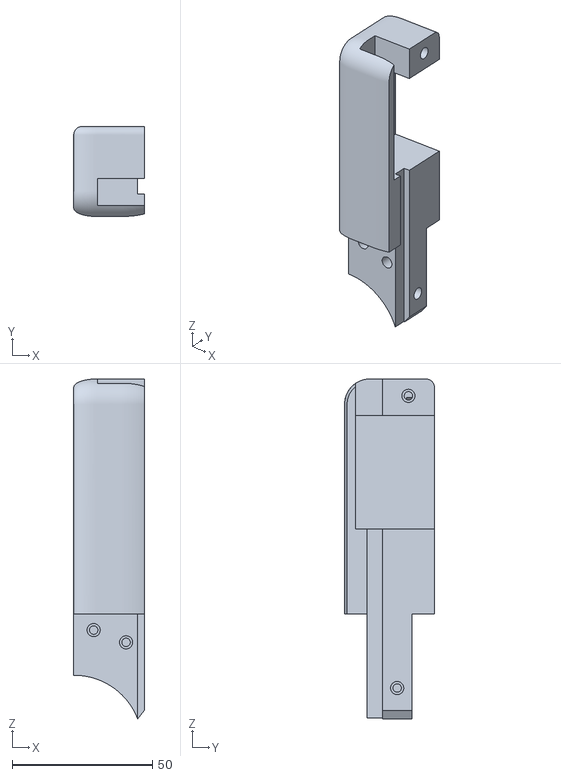
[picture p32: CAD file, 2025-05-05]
3d-models/legs/left/leg/left-leg.stl
25.2 x 32.1 x 121.3

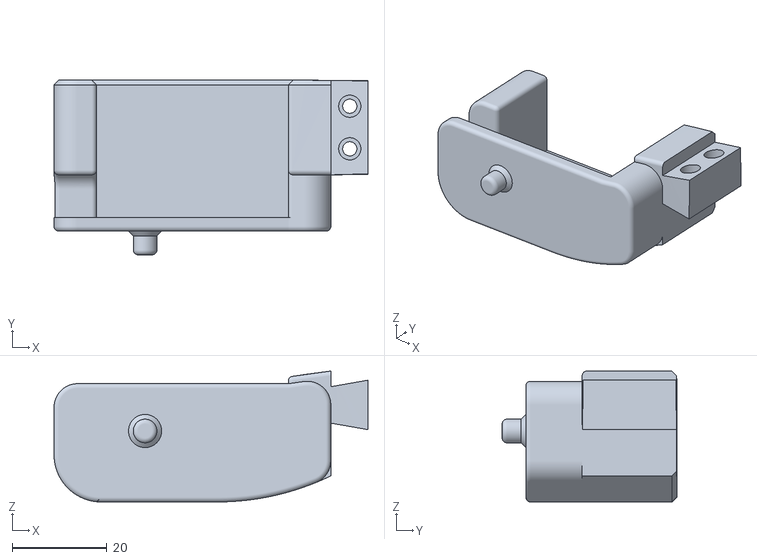
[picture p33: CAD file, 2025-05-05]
3d-models/legs/right/foot/right-foot-base.stl
66.4 x 36.9 x 27.7

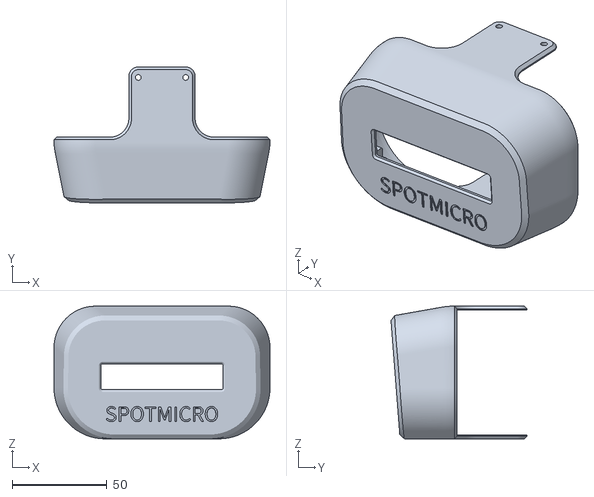
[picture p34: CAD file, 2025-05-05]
3d-models/rear/rear-cover.stl
114.0 x 71.8 x 70.0

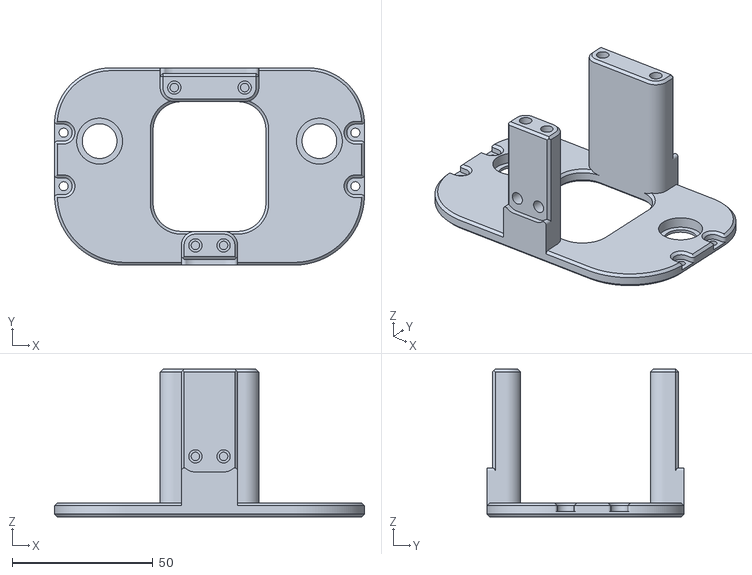
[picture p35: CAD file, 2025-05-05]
3d-models/shoulders/inner-plate/inner-shoulder-plate.stl
110.0 x 70.0 x 52.5

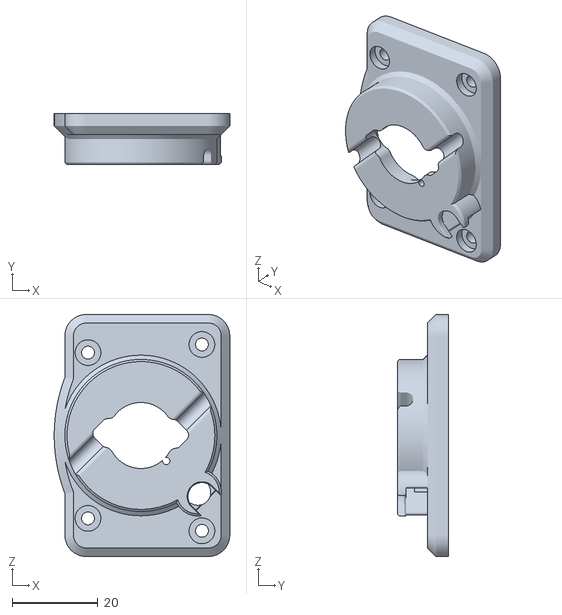
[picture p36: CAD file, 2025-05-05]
3d-models/shoulders/limb/left/left-shoulder-limb-cover.stl
41.0 x 12.0 x 56.5

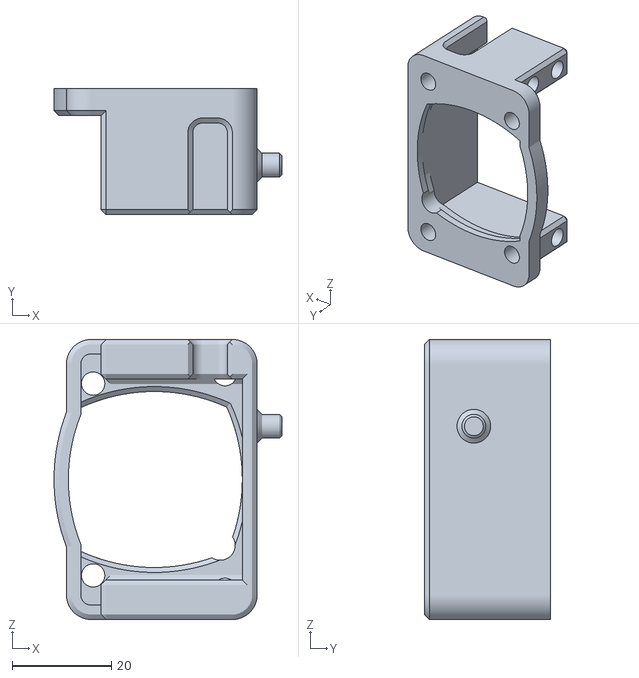
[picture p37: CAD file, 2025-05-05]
3d-models/shoulders/limb/right/right-shoulder-limb.stl
46.0 x 25.5 x 56.5

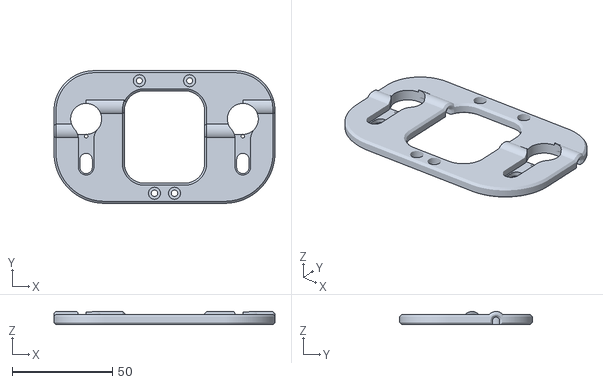
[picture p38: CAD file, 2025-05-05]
3d-models/shoulders/outer-plate/outer-shoulder-plate.stl
110.0 x 66.0 x 6.50

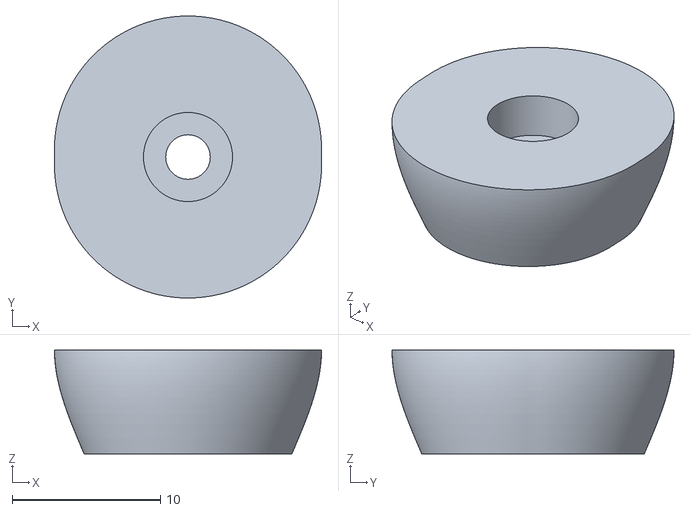
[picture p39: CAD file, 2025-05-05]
3d-models/stand/foot-x4.stl
18.0 x 19.0 x 7.00

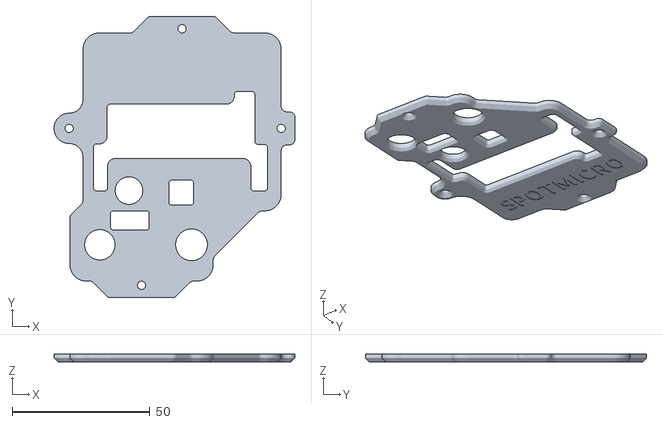
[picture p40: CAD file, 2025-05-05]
3d-models/body/boards-cover.stl
87.4 x 102.0 x 3.00

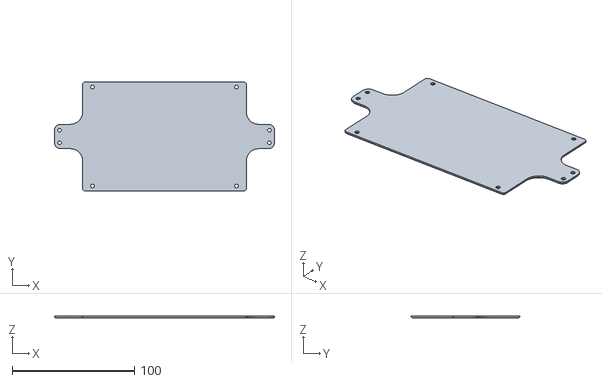
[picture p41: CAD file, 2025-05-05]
3d-models/bottom/bottom-panel.stl
180.1 x 89.0 x 2.00

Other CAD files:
3d-models/legs/right/leg/right-leg.stl
3d-models/head/nose.stl
3d-models/legs/left/foot/left-foot-base.stl
3d-models/body/sbec-cover.stl
3d-models/body/side.stl
3d-models/bottom/left-side-panel.stl
3d-models/bottom/offset.stl
3d-models/head/connector.stl
3d-models/head/face.stl
3d-models/legs/left/foot/left-foot-inner.stl
3d-models/legs/left/leg/bearing-end.stl
3d-models/legs/left/leg/cover.stl
3d-models/legs/left/leg/servo-end.stl
3d-models/legs/right/foot/right-foot-inner.stl
3d-models/legs/right/foot/right-foot-outer.stl
3d-models/legs/right/leg/bearing-end.stl
3d-models/legs/right/leg/cover.stl
3d-models/legs/right/leg/servo-end.stl
3d-models/shoulders/limb/left/left-shoulder-limb.stl
3d-models/shoulders/limb/right/right-shoulder-limb-cover.stl
3d-models/stand/base-x2.stl
3d-models/stand/cross-beam-x2.stl
3d-models/stand/fork-x2.stl
3d-models/stand/stem-x2.stl
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

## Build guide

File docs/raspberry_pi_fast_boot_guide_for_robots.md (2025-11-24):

# Fast-Boot Linux Guide for Raspberry Pi Robots (Wi‑Fi + Bluetooth)

This guide shows you how to turn a Raspberry Pi–based robot into a **fast-booting, headless machine** while keeping **Wi‑Fi and Bluetooth** working.

You’ll learn how to:

- Measure boot time and find the biggest time-wasting services
- Switch from graphical to text-mode boot
- Disable or remove heavyweight services (Snap, cloud-init, ModemManager, etc.)
- Tweak Pi boot settings
- Add your robot app as a systemd service
- Measure progress after each change

The examples assume **Ubuntu on Raspberry Pi**, but almost everything applies to other systemd-based distros (including Raspberry Pi OS) with minor path/name changes.

---

## 1. Prerequisites & Safety

### 1.1. What you need

- A Raspberry Pi (4/5 or similar) running a systemd-based Linux (Ubuntu Server or Raspberry Pi OS Lite recommended)
- Shell access (keyboard + monitor, or SSH)
- A backup or SD card image you can restore if something goes wrong

### 1.2. Safety principles

Before you start disabling services, keep these rules in mind:

- **Change one thing at a time.** After each change, reboot and re-measure.
- **Never disable core systemd components** like `systemd-udevd`, `dbus`, `systemd-logind`, `systemd-journald`.
- **Don’t disable your network or SSH** unless you’re absolutely sure you won’t need remote access.
- Keep notes so you can undo changes (or turn them into a reproducible setup script later).

---

## 2. Measure Boot Time (Baseline)

First, get your baseline boot performance. Reboot the Pi, log in, then run:

```bash
systemd-analyze
```

Sample output:

```text
Startup finished in 6.325s (kernel) + 13.858s (userspace) = 20.183s
```

- **Kernel**: Time from power-on to when the Linux kernel hands control to userspace
- **Userspace**: Time from PID 1 (systemd) startup to reaching the default target (multi-user or graphical)

### 2.1. Find long-running services

List services ordered by how long they took to start:

```bash
systemd-analyze blame
```

You’ll get lines like:

```text
5.992s snapd.seeded.service
5.786s snapd.service
5.047s networkd-dispatcher.service
3.659s cloud-init-main.service
3.145s ssh.service
...
```

The top items are your **prime candidates** for optimization or removal.

### 2.2. See the critical boot chain

Not every long-running service actually delays reaching the target. To see what blocks the boot path:

```bash
systemd-analyze critical-chain
```

This shows which services are on the critical path from boot to the default target.

You’ll refer back to these commands **after each round of changes** to confirm that boot time is improving.

---

## 3. Switch to Text-Mode Boot (No GUI)

Robots almost never need a full desktop environment. Booting to a text console shaves off time and memory usage.

### 3.1. Set the default target to multi-user

```bash
sudo systemctl set-default multi-user.target
```

Reboot:

```bash
sudo reboot
```

After reboot, check:

```bash
systemd-analyze
systemd-analyze critical-chain
```

You should see something like:

```text
multi-user.target reached after Xs in userspace
```

instead of `graphical.target`. This alone can make a noticeable difference on desktop-leaning images.

If you ever need the GUI back:

```bash
sudo systemctl set-default graphical.target
sudo reboot
```

---

## 4. Eliminate Heavy Services (Snap, cloud-init, ModemManager, etc.)

This section targets services that commonly appear near the top of `systemd-analyze blame` but are not needed for a headless robot.

> **Important:** Always confirm with `systemd-analyze blame` which services are actually slow on your system before disabling them.

### 4.1. Snap (snapd & snapd.seeded)

On Ubuntu, **Snap** is a major contributor to userspace boot time.

You’ll often see things like:

```text
5.992s snapd.seeded.service
5.786s snapd.service
```

If your robot **does not rely on snap packages**, you can disable Snap completely.

#### 4.1.1. Disable Snap services

```bash
sudo systemctl disable --now snapd.service snapd.seeded.service
```

Reboot and recheck:

```bash
sudo reboot
# then after login
systemd-analyze
systemd-analyze blame | head -20
```

You should no longer see `snapd` entries, and userspace boot time should drop significantly.

#### 4.1.2. (Optional) Remove snapd

Once you’re sure nothing uses Snap:

```bash
sudo apt purge snapd
```

This will free disk space and prevent Snap from coming back in future updates.

---

### 4.2. Cloud-Init

On many cloud images, **cloud-init** configures the system at first boot. On a Pi robot, it’s usually dead weight after initial setup and can add several seconds to boot.

You might see services like:

- `cloud-init.service`
- `cloud-init-local.service`
- `cloud-config.service`
- `cloud-final.service`

Often one of them shows prominently in `systemd-analyze blame`, e.g.:

```text
3.659s cloud-init-main.service
```

#### 4.2.1. Disable cloud-init

```bash
sudo systemctl disable --now \
  cloud-init.service \
  cloud-init-local.service \
  cloud-config.service \
  cloud-final.service
```

Reboot and re-measure.

#### 4.2.2. (Optional) Remove cloud-init

When you’re confident the system no longer depends on it:

```bash
sudo apt purge cloud-init
```

---

### 4.3. ModemManager (3G/4G modems)

If your robot only uses **Wi‑Fi and Bluetooth** (no cellular modem), you can safely remove **ModemManager**.

You might see:

```text
1.371s ModemManager.service
```

Disable it:

```bash
sudo systemctl disable --now ModemManager.service
```

Reboot and check that Wi‑Fi/Bluetooth still work. ModemManager is only for mobile broadband devices.

---

### 4.4. Optional: Other “Nice-to-Have” Services

These services can also add a bit of time. You can disable them **if you understand the trade-offs** and don’t rely on their functionality.

#### 4.4.1. Apport (crash reporter)

Ubuntu’s crash reporting service:

```bash
sudo systemctl disable --now apport.service
```

You’ll lose automatic crash popups/uploading, but your robot doesn’t need popups.

#### 4.4.2. Pollinate (entropy seeding)

Pollinate contacts Ubuntu’s infrastructure to help seed randomness:

```bash
sudo systemctl disable --now pollinate.service
```

For an offline robot, this is usually unnecessary.

#### 4.4.3. e2scrub (filesystem scrubber)

This helps monitor and scrub ext4 filesystems. If your robot is on a reasonably reliable SD card and you shut down cleanly, you can disable it for faster boots:

```bash
sudo systemctl disable --now e2scrub_reap.service
sudo systemctl disable --now e2scrub_all.timer 2>/dev/null || true
```

You’ll lose automated advanced filesystem scrubbing, but basic `fsck` on boot still protects you from many issues.

#### 4.4.4. udisks2 (auto-mounting removable drives)

If you never plug USB sticks into your robot at runtime:

```bash
sudo systemctl disable --now udisks2.service
```

#### 4.4.5. Avahi & printing (desktop conveniences)

If you see services like:

- `avahi-daemon.service` (mDNS / .local hostname discovery)
- `cups.service`, `cups-browsed.service` (printing)

You can disable them on a headless robot:

```bash
sudo systemctl disable --now avahi-daemon.service
sudo systemctl disable --now cups.service cups-browsed.service
```

Only keep Avahi if you rely on `.local` hostnames for discovery.

---

## 5. Network Tuning for Faster Boot

Network startup can also delay boot, especially if the system waits for an IP address before proceeding.

### 5.1. Avoid waiting too long for “network-online”

Many services specify:

```ini
After=network-online.target
Wants=network-online.target
```

This can slow boot if `systemd-networkd-wait-online` or similar takes several seconds.

If your robot application can tolerate the network coming up slightly later, use:

```ini
After=network.target
```

instead of `network-online.target` in your own systemd service units.

### 5.2. Use static IP for Wi‑Fi (Ubuntu with Netplan)

If your Pi gets its IP via DHCP, boot can be delayed while waiting for a lease. A static IP makes network bring-up more deterministic.

Edit your Netplan file, e.g.:

```bash
sudo nano /etc/netplan/01-netcfg.yaml
```

Example static Wi‑Fi configuration (adjust to match your network):

```yaml
network:
  version: 2
  wifis:
    wlan0:
      access-points:
        "YourSSID":
          password: "YourPassword"
      dhcp4: no
      addresses: [192.168.1.50/24]
      gateway4: 192.168.1.1
      nameservers:
        addresses: [1.1.1.1,8.8.8.8]
```

Apply the configuration:

```bash
sudo netplan apply
```

Reboot and re-measure boot with `systemd-analyze`.

> **Note:** Details vary if you’re using NetworkManager instead of Netplan/systemd-networkd, but the principle is the same—reduce DHCP delay and unnecessary "wait-online" behavior.

---

## 6. Run Your Robot App as a Systemd Service

To make your robot responsive as soon as possible after boot, run your robot control software as a **systemd service**.

### 6.1. Create a service unit

Assume your robot app entrypoint is `/home/pi/robot/main.py` and it needs basic networking and Bluetooth, but can start without waiting for full "network-online":

Create a new unit file:

```bash
sudo nano /etc/systemd/system/robot.service
```

Example unit:

```ini
[Unit]
Description=Robot control stack
After=bluetooth.target network.target
Wants=bluetooth.target

[Service]
Type=simple
User=pi
WorkingDirectory=/home/pi/robot
ExecStart=/usr/bin/python3 /home/pi/robot/main.py
Restart=on-failure

[Install]
WantedBy=multi-user.target
```

Save and enable it:

```bash
sudo systemctl daemon-reload
sudo systemctl enable robot.service
```

Reboot and verify:

```bash
sudo reboot
# after boot
systemctl status robot.service
```

Your robot stack should now start automatically early in the boot sequence, right after basic networking and Bluetooth are available.

---

## 7. Raspberry Pi–Specific Boot Tweaks

On Ubuntu for Raspberry Pi, the firmware and boot configuration typically live under `/boot/firmware`. On Raspberry Pi OS, they’re usually in `/boot`.

### 7.1. Remove boot delay and splash

Edit the Pi boot configuration:

```bash
sudo nano /boot/firmware/config.txt
```

Add (or adjust) these settings:

```ini
# Don’t delay at boot
boot_delay=0

# Disable the rainbow splash screen (optional)
disable_splash=1
```

If you don’t use the serial console for debugging, you can also disable UART to slightly streamline boot:

```ini
enable_uart=0
```

(Leave `enable_uart=1` if you use serial logs or console.)

### 7.2. Disable unused onboard audio

If your robot doesn’t use the Pi’s onboard audio:

```ini
# In /boot/firmware/config.txt or usercfg.txt
dtparam=audio=off
```

This removes unnecessary audio init.

> **Note:** If you are on Raspberry Pi OS, these settings might go in `/boot/config.txt` instead of `/boot/firmware/config.txt`. The idea is the same.

Reboot and verify that everything still works, then re-run `systemd-analyze` to see the cumulative effect.

---

## 8. Measure Progress and Iterate

After each batch of changes, repeat your measurements:

```bash
systemd-analyze
systemd-analyze blame | head -20
systemd-analyze critical-chain
```

Track:

- **Kernel time** – mainly affected by firmware and kernel; big changes here require kernel/bootloader tweaks or custom images.
- **Userspace time** – the main thing you’re tuning by disabling services and simplifying boot.
- **Which services still dominate** in `systemd-analyze blame`.

Aim for:

- No unnecessary heavyweight services (no `snapd*`, `cloud-init*`, etc. unless you truly need them)
- A **multi-user (text) target** instead of `graphical.target`
- Your robot app running as a **systemd service** started early in the boot process

---

## 9. Going Even Further: Custom Minimal Images

If you need **extreme** boot speed (e.g. a couple of seconds from power-on to robot ready), consider:

- **Buildroot** or **Yocto** to build a custom, minimal Linux image:
  - Stripped-down kernel
  - BusyBox userland
  - Only your robot app + core drivers

This is more complex and beyond the scope of this guide, but the concepts are the same:

1. Minimize services
2. Minimize drivers
3. Start your application as early as possible

For many Raspberry Pi robots, however, a carefully trimmed Ubuntu Server or Raspberry Pi OS Lite using the steps above strikes a great balance between **boot speed**, **maintainability**, and **developer comfort**.

---

## 10. Summary Checklist

Use this quick checklist to turn a stock Pi system into a fast-boot robot controller:

- [ ] Measure baseline with `systemd-analyze`, `blame`, and `critical-chain`
- [ ] Switch to `multi-user.target` (no GUI)
- [ ] Disable Snap (`snapd.service`, `snapd.seeded.service`) if unused
- [ ] Disable Cloud-Init once setup is done
- [ ] Disable ModemManager if no cellular modem is used
- [ ] Optionally disable Apport, Pollinate, e2scrub, udisks2, Avahi, CUPS, etc.
- [ ] Tune networking to avoid long `wait-online` delays (static IPs where possible)
- [ ] Add your robot app as a systemd service that starts after basic network/BT
- [ ] Tweak Pi boot config (no boot delay, optional no splash, optional no audio)
- [ ] Re-measure and iterate until boot time meets your requirements

You can adapt this structure directly into a blog post, README, or project documentation for your robot platform.

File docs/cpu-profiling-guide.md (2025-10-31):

# Raspberry Pi CPU Profiling Guide

## Overview
This guide explains how to monitor CPU usage of a Python-based robotics program on a Raspberry Pi using three simultaneous SSH sessions:
1. **Session 1:** Runs the robot code.
2. **Session 2:** Monitors live CPU usage with `htop`.
3. **Session 3:** Profiles Python function-level CPU hotspots with `py-spy`.

---

## 1. SSH Sessions Setup
Open **three separate SSH connections** to your Raspberry Pi, for example:
```bash
ssh pi@spotmicroai.local
ssh pi@spotmicroai.local
ssh pi@spotmicroai.local
```
Each will be used for a different tool.

---

## 2. Session 1 – Run Your Code
Activate your virtual environment and start your main Python script:
```bash
cd ~/spotmicroai
source venv/bin/activate
./runtime.sh
```
Confirm it’s running in the background and note its PID:
```bash
pgrep -f spotmicroai/main.py
```

---

## 3. Session 2 – Monitor System Load (htop)
Start **htop** to monitor system-wide CPU, memory, and process usage:
```bash
htop
```
Key controls inside `htop`:
- `F6` → Sort by CPU%
- `F5` → Toggle Tree view (off for global sort)
- `H`  → Toggle Threads view
- `q`  → Quit

Watch for your process (e.g. `venv/bin/python3 spotmicroai/main.py`) and note the CPU%.

---

## 4. Session 3 – Profile Python Code (py-spy)
Install `py-spy` if not already:
```bash
source ~/spotmicroai/venv/bin/activate
pip install py-spy
```
Run it against the process ID from Session 1:
```bash
sudo /home/pi/spotmicroai/venv/bin/py-spy top --pid <PID>
```
Observe the top functions consuming CPU.

To record a flamegraph for 10 seconds:
```bash
sudo /home/pi/spotmicroai/venv/bin/py-spy record -o profile.svg --pid <PID> --duration 10
```
Then copy the file back to your desktop and open it:
```bash
scp pi@spotmicroai.local:~/spotmicroai/profile.svg .
```

---

## 5. Interpreting Results
| Tool | What to Look For | Typical Action |
|---|---|---|
| **htop** | High CPU from `main.py` even when idle | Indicates busy loop |
| **py-spy** | Top function names (e.g., `do_process_events_from_queues`, `move`) | Add small `time.sleep()` or blocking queue read |

---

## 6. Recommended Loop Adjustment
If your idle loop runs constantly, throttle it:
```python
while True:
    event = queue.get(timeout=0.01)  # blocks briefly
    handle_event(event)
```
This prevents 100% CPU when the robot is inactive.

---

## Summary
| Session | Purpose | Key Command |
|---|---|---|
| 1 | Run your code | `./runtime.sh` |
| 2 | Watch system load | `htop` |
| 3 | Profile code | `sudo py-spy top --pid <PID>` |

Once you’ve identified the busy function, optimize it and repeat to confirm CPU drops when idle.

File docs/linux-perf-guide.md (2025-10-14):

# Raspberry Pi Performance & Throttling Debugging Guide

This guide provides a comprehensive procedure for investigating and debugging performance, throttling, and responsiveness issues on Raspberry Pi devices. It is designed for developers maintaining field-deployed systems or diagnosing slow behavior.

---

## 1. Overview
When your Raspberry Pi feels sluggish, freezes for several seconds, or behaves unpredictably, the cause usually falls into one of these categories:
- **CPU bottlenecks** (processes overloading cores)
- **Memory exhaustion or swap thrashing**
- **SD card I/O latency or filesystem corruption**
- **Power supply or thermal throttling**

The following sections outline step-by-step methods to identify and fix these issues.

---

## 2. Checking CPU Utilization

### Commands
```bash
top
# or, for better visualization
htop
```

### Interpretation
- **High %CPU on one process**: That process dominates a single core.
- **wa (I/O wait)**: Indicates the CPU is waiting for slow disk or network I/O.
- **load average**: Roughly, the number of runnable or waiting processes. A load higher than the number of cores (>4 on a Pi Zero 2 W) suggests overload.

### Recommendations
- Identify high-usage processes and inspect their logs or code.
- Use `nice` or `systemd` service limits to reduce CPU priority.
- For Python services, check for tight loops or unbounded polling.

---

## 3. Checking Memory Usage

### Commands
```bash
free -h
```

### Interpretation
| Column | Meaning |
|---|---|
| **used** | Total RAM consumed by programs |
| **available** | RAM still available without swapping |
| **Swap used** | Nonzero means memory pressure |

If swap usage > 0 and available < 50 MB, you are thrashing the SD card.

### Recommendations
- Increase swap file size:
  ```bash
  sudo nano /etc/dphys-swapfile
  CONF_SWAPSIZE=512
  sudo dphys-swapfile setup && sudo systemctl restart dphys-swapfile
  ```
- Optimize Python or Node.js processes to release unused memory.

---

## 4. Checking Temperature and Power Throttling

### Commands
```bash
vcgencmd measure_temp
vcgencmd get_throttled
```

### Interpretation
- **Temperature output:** Normal < 65°C, throttling risk > 80°C.
- **Throttled flag:**
  - `throttled=0x0` means normal operation.
  - Non-zero indicates under-voltage or thermal throttling.

### Recommendations
- Ensure a **5V 2.5A+** power supply and quality cable.
- Add a heatsink or small fan if under sustained load.

---

## 5. Checking SD Card Performance and Health

### Commands
Install utilities:
```bash
sudo apt install sysstat
```
Then run:
```bash
iostat -xz 1 3
```

### Interpretation
| Metric | Meaning | Healthy Range |
|---|---|---|
| **r_await / w_await** | Average read/write latency | < 5 ms |
| **%util** | Disk utilization | < 90% sustained |
| **wareq-sz** | Write request size | Consistent values (~32–512 KB) |

If `w_await > 50 ms` or high I/O wait (`%iowait` > 10%), the SD card is slowing the system.

### Test raw write speed
```bash
dd if=/dev/zero of=/tmp/test bs=4M count=20 conv=fdatasync
```
Expected result: **> 10 MB/s** for a healthy card.

### Check filesystem and kernel logs
```bash
sudo dmesg | egrep -i "mmc|error|fail|timeout|ext4"
```
If you see messages like `orphan cleanup` or `read-only fs`, the filesystem is recovering from corruption.

### Recommendations
- Replace slow or damaged SD cards.
- Mount filesystems with `noatime` to reduce writes:
  ```bash
  PARTUUID=<id>  /  ext4  defaults,noatime  0  1
  ```
- Move logs to RAM to reduce wear:
  ```bash
  tmpfs /tmp tmpfs defaults,noatime,nosuid,size=64m 0 0
  tmpfs /var/log tmpfs defaults,noatime,nosuid,size=64m 0 0
  ```

---

## 6. Investigating Boot and Journal Logs

### Commands
```bash
sudo journalctl -b -1 -p 0..3
sudo journalctl -p err -S -2h
```

### Interpretation
- `-b -1`: Shows previous boot (useful after a crash).
- `-p 0..3`: Shows only errors and critical issues.
- Look for repeated service restarts or kernel panics.

If the Pi silently rebooted, check:
```bash
last -x | head
```

---

## 7. Checking for I/O or DNS Blocking

### Tests
```bash
time ls /
time hostname -f
```
If `hostname -f` stalls, add this line to `/etc/hosts`:
```
127.0.1.1   raspberrypi
```
This avoids slow reverse DNS lookups that can freeze `sudo` and other commands.

---

## 8. Recommended High-Performance SD Cards

| Brand / Model | Type | Performance Tier | Notes |
|---|---|---|---|
| **SanDisk Extreme microSDXC UHS-I** | A2 / U3 / V30 | ★★★★★ | Excellent random I/O; balanced speed and endurance |
| **Samsung PRO Plus microSDXC** | A2 / U3 / V30 | ★★★★★ | Great sustained writes and reliability |
| **Kingston High Endurance** | A1 / U3 | ★★★★☆ | Designed for heavy write cycles |
| **PNY PRO Elite High Endurance** | A2 / V30 | ★★★★☆ | Good value endurance card |
| **ProGrade Digital UHS-II microSDXC** | UHS-II / V60 | ★★★★☆ | Backward compatible; very high speed |
| **VIOFO Industrial Grade microSD** | U3 / A2 / V30 | ★★★★★ | Industrial spec; great for robotics and harsh environments |

### Buying Tips
- Prefer **A1 or A2** rated cards (optimized for random access).
- Avoid no-name or fake cards (common on marketplaces).
- Use **64–256 GB** capacity for best performance/wear balance.
- Always benchmark new cards using `dd` or `fio` after flashing.

---

## 9. General Optimization Tips
- Disable HDMI if unused:
  ```bash
  sudo /usr/bin/tvservice -o
  ```
- Minimize logging or move logs to a remote syslog.
- Avoid unnecessary background services:
  ```bash
  systemctl list-unit-files --type=service | grep enabled
  sudo systemctl disable <service>
  ```

---

## 10. Quick Diagnostic Summary
| Subsystem | Key Command | Healthy Range / Result |
|---|---|---|
| CPU | `top` / `htop` | < 80% sustained usage |
| Memory | `free -h` | > 50 MB available, no swap use |
| Power | `vcgencmd get_throttled` | `throttled=0x0` |
| SD I/O | `iostat -xz 1 3` | `w_await < 5ms`, `%util < 90%` |
| Write speed | `dd` test | > 10 MB/s |
| Errors | `dmesg | egrep -i "mmc|error|fail"` | none |

---

### Author’s Note
This guide was derived from real-world diagnostics on Raspberry Pi Zero 2 W systems used in robotics deployments. The commands and interpretations apply to all Raspberry Pi models running Debian Bookworm or

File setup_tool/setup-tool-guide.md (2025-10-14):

# SpotmicroAI Development Deployment Guide

## Overview

The setup tool now supports efficient code deployment for development workflows. After initial setup, you can quickly sync code changes to your Raspberry Pi using `rsync`.

## Usage Modes

### 1. Initial Setup (First Time)
```bash
./setup.sh
```
This will:
- Configure SSH connection
- Set up SSH keys for passwordless authentication
- Update system packages
- Install Python and dependencies
- Copy all project files
- Configure the environment

### 2. Development Mode (Sync Changes)
```bash
./setup.sh
```
or explicitly:
```bash
./setup.sh --deploy
```

After initial setup is complete, running `./setup.sh` will automatically sync your changes.

This will:
- Sync only changed files using `rsync`
- Preserve timestamps and permissions
- Delete remote files that don't exist locally
- Exclude unnecessary files (`.git`, `__pycache__`, `*.pyc`, `venv`, `*.log`)
- Set executable permissions on shell scripts

### 3. Clean Setup (Start Fresh)
```bash
./setup.sh --clean
```
This will clear all saved configuration and start from scratch.

## Development Workflow

1. **Initial Setup** (one time):
   ```bash
   cd ~/Spotmicro4/src
   ./setup.sh
   ```

2. **Make Code Changes** locally in your editor

3. **Deploy Changes** to Raspberry Pi:
   ```bash
   ./setup.sh --deploy
   ```
   or just:
   ```bash
   ./setup.sh
   # Then select option 1
   ```

4. **Test on Raspberry Pi**:
   ```bash
   ssh pi@spotmicroai.local
   cd ~/spotmicroai
   ./run.sh
   ```

## Benefits of rsync

- **Delta Sync**: Only transfers the **changed parts** of files (not full copies!)
- **Speed**: Skips unchanged files entirely
- **Efficiency**: Compresses data during transfer
- **Safety**: Preserves file attributes and permissions
- **Clean**: Automatically removes deleted files on remote
- **Smart**: Excludes development artifacts automatically

### How Delta Sync Works

rsync uses a sophisticated algorithm to:
1. Compare file checksums between local and remote
2. Only transfer the **byte-level differences** (deltas)
3. Skip files that haven't changed at all

This means if you change one line in a 1000-line file, rsync only transfers that change, not the entire file!

## What Gets Synced

✅ **Included:**
- Python source files (`*.py`)
- Shell scripts (`*.sh`)
- Configuration files (`*.json`)
- README and documentation
- All project directories

❌ **Excluded:**
- `.git` directory
- `__pycache__` directories
- `*.pyc` compiled Python files
- `venv` virtual environment
- `*.log` log files

## Requirements

- `rsync` must be installed on your development machine
  - **Ubuntu/Debian**: `sudo apt-get install rsync`
  - **macOS**: `brew install rsync` (or use built-in)
  - **Windows**: Use WSL or Git Bash with rsync

## Troubleshooting

### "rsync command not found"
Install rsync on your development machine:
```bash
sudo apt-get install rsync  # Ubuntu/Debian
brew install rsync          # macOS
```

### Still asks for password
Ensure SSH keys are set up correctly:
```bash
./setup.sh --clean  # Start fresh
./setup.sh          # Set up SSH keys
```

### Files not syncing
Check that you're in the correct directory:
```bash
cd ~/Spotmicro4/src
./setup.sh --deploy
```

## Advanced Usage

### Manual rsync
You can also use rsync directly:
```bash
rsync -avz --delete \
  --exclude="__pycache__" --exclude="*.pyc" \
  -e "ssh -i ~/.ssh/id_rsa" \
  robot/ pi@spotmicroai.local:~/spotmicroai/
```

### Dry Run (see what would be synced)
```bash
rsync -avzn --delete \
  --exclude="__pycache__" --exclude="*.pyc" \
  -e "ssh -i ~/.ssh/id_rsa" \
  robot/ pi@spotmicroai.local:~/spotmicroai/
```
(Note the `-n` flag for dry-run)

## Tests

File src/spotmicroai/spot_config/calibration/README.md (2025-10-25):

# SpotMicroAI Servo Calibration Guide

## Overview

This directory contains the servo calibration system for SpotMicroAI. The calibration wizard provides an interactive, step-by-step guide for calibrating each servo joint to ensure precise and consistent movement across the robot.

## Calibration System

The calibration system uses a two-point reference approach to establish accurate servo pulse-width mappings:

1. **Point 1**: Initial reference position
2. **Point 2**: Secondary reference position

These points are used to perform linear extrapolation and determine the full operational range of each servo.

## Joint Types and Specifications

### Shoulder Servos

Shoulder servos control the lateral positioning of the front and rear legs. The calibration range spans from 60° to 120°, with a resting position of 90°.

#### FRONT-LEFT-SHOULDER & REAR-LEFT-SHOULDER
- **Pulse-Angle Relationship**: Increasing pulse width lowers the angle
- **Rest Angle**: 90° (fixed)
- **Operating Range**: 60° – 120°
- **Range Size**: 60°

#### REAR-RIGHT-SHOULDER & FRONT-RIGHT-SHOULDER
- **Pulse-Angle Relationship**: Increasing pulse width increases the angle
- **Rest Angle**: 90° (fixed)
- **Operating Range**: 60° – 120°
- **Range Size**: 60°

### Leg Servos

Leg servos control the knee joint, allowing the legs to flex and extend. Two configurations exist depending on the leg position.

#### Configuration 1 (FRONT-LEFT-LEG & REAR-LEFT-LEG)
- **Pulse-Angle Relationship**: Increasing pulse width increases the angle
- **Rest Angle**: 90° (fixed)
- **Operating Range**: –20° – 110°
- **Range Size**: 130°

#### Configuration 2 (FRONT-RIGHT-LEG & REAR-RIGHT-LEG)
- **Pulse-Angle Relationship**: Increasing pulse width lowers the angle
- **Rest Angle**: 90° (fixed)
- **Operating Range**: –20° – 110°
- **Range Size**: 130°

### Foot Servos

Foot servos control the ankle joint, allowing for vertical foot positioning. The calibration range spans from 17° to 131°, with a resting position of 17°.

#### FRONT-LEFT-FOOT & REAR-LEFT-FOOT
- **Pulse-Angle Relationship**: Increasing pulse width increases the angle
- **Rest Angle**: 17° (fixed)
- **Operating Range**: 17° – 131°
- **Range Size**: 114°

#### FRONT-RIGHT-FOOT & REAR-RIGHT-FOOT
- **Pulse-Angle Relationship**: Increasing pulse width lowers the angle
- **Rest Angle**: 17° (fixed)
- **Operating Range**: 17° – 131°
- **Range Size**: 114°

## Usage

### Interactive Calibration Wizard

To calibrate a single servo, run:

```bash
python calibration_wizard.py <SERVO_ID>
```

Example:
```bash
python calibration_wizard.py front_left_shoulder
```

### Calibrate All Servos

To calibrate all servos sequentially:

```bash
python calibration_wizard.py all
```

### Valid Servo IDs

- `front_left_shoulder`
- `front_right_shoulder`
- `rear_left_shoulder`
- `rear_right_shoulder`
- `front_left_leg`
- `front_right_leg`
- `rear_left_leg`
- `rear_right_leg`
- `front_left_foot`
- `front_right_foot`
- `rear_left_foot`
- `rear_right_foot`

## Calibration Process

1. **Launch the Wizard**: Start the calibration wizard for your target servo
2. **Review Instructions**: Read the joint-specific instructions
3. **Capture Point 1**: Position the servo at the first reference angle and capture
4. **Capture Point 2**: Position the servo at the second reference angle and capture
5. **Confirm Values**: Review the calculated calibration parameters
6. **Save Configuration**: Save the calibration data to persistent storage

## Key Features

- **Interactive CLI Interface**: Real-time visual feedback with pulse width adjustments
- **Fine-Grained Control**: Adjust servo position in 10µs increments
- **Linear Extrapolation**: Accurate calibration across the entire servo range
- **Configuration Persistence**: Calibration data saved to JSON configuration files
- **Servo Recreation**: Servos are automatically recreated with new calibration parameters after saving

## Important Notes

- **Rest Angles Are Fixed**: Each joint type has a fixed rest angle that should not be changed
- **Operating Ranges Are Fixed**: The min and max angle limits for each joint are fixed and should not be modified
- **Physical vs. Local Coordinates**: Calibration uses physical angle coordinates, which are automatically converted to servo local coordinates
- **Two-Point Calibration**: Accurate calibration requires precise positioning at both reference points

## Files

- `calibration_wizard.py` - Interactive calibration wizard
- `servo_controller.py` - Low-level servo control interface
- `calibration_specs.py` - Joint type specifications and calibration constants
- `servo_manual_control.py` - Manual servo testing and debugging tool

## Troubleshooting

**Servo doesn't move to rest position after calibration:**
- Ensure both calibration points were captured at the correct physical angles
- Verify that the servo pulse range is within the hardware's safe operating limits

**Calibration wizard crashes or becomes unresponsive:**
- Check that the servo hardware is properly connected
- Verify the PCA9685 I2C board is accessible
- Ensure no other processes are accessing the servo hardware

**Inaccurate servo movement:**
- Re-run calibration and verify precise positioning at both reference points
- Check for servo hardware issues or mechanical binding

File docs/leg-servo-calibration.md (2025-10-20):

### Servo Calibration Guide (Generic Procedure)

This guide explains how to calibrate any hobby servo motor for precise angle control using the Adafruit `servo.Servo()` class. It provides a step-by-step process for determining pulse width limits, mapping them to physical angles, and configuring your code. Example values are provided for reference.

---

### 1. Measure Physical Angle and Pulse Width

Start by moving your servo through its full *safe* range of motion. Use an angle measurement tool (or digital inclinometer) to determine the physical angles corresponding to the minimum and maximum commandable positions.

Record the PWM pulse width values (in microseconds) reported at each position.

| Example Physical Position | Example Angle (°) | Example Pulse (µs) |
|---|---|---|
| Backward limit | -20 | 1463 |
| Vertical (neutral) | 0 | 1611 |
| Forward limit | +110 | 2441 |

> Note: Your angles and pulse widths will differ depending on servo model, linkage geometry, and mechanical constraints.

---

### 2. Determine the Physical Span

Compute the total physical span of motion:

\[ \text{span} = \theta_{max} - \theta_{min} \]

In the example above:

\[ 110 - (-20) = 130° \]

This span will be used as the servo’s `actuation_range`.

---

### 3. Configure the Adafruit Servo Object

The Adafruit `servo.Servo()` object maps angles linearly between two pulse widths:
- `min_pulse` → PWM width at **0°**
- `max_pulse` → PWM width at **actuation_range°**
- `actuation_range` → total logical angle range (degrees)

Example configuration:

```python
s = servo.Servo(
    board.get_channel(config.channel),
    min_pulse=1463,   # example minimum pulse width (µs)
    max_pulse=2441,   # example maximum pulse width (µs)
    actuation_range=130,  # example total range (°)
)
```

---

### 4. Verify the Mapping

Command a few known angles and check their physical positions:

| Example Command | Expected Physical Angle |
|---|---|
| `s.angle = 0` | -20° (backward limit) |
| `s.angle = 20` | 0° (vertical) |
| `s.angle = 130` | +110° (forward limit) |

Adjust `min_pulse` and `max_pulse` slightly if necessary to align the servo precisely with your physical endpoints.

---

### 5. Notes for Safe Calibration
- Always disconnect load-bearing linkages during calibration to avoid stress on servo arms.
- Do **not** exceed your servo’s safe physical limits — mechanical stalls can damage gears.
- Some servos exhibit non-linear behavior near extremes; perform fine-tuning near mid-range for best accuracy.
- Repeat this procedure for each servo individually, as tolerances vary between units.

---

By following this procedure, any hobbyist or developer can accurately calibrate servo limits for use in robotic legs, arms, or other motion-control projects, ensuring smooth, predictable movement across the servo’s safe range.

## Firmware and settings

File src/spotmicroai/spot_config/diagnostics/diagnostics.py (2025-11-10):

#!/usr/bin/env python3
"""
Diagnostics wizard for SpotMicroAI servo symmetry testing.

Interactive guided diagnostics to test all servos by sweeping them through
their range of motion to verify symmetry and proper operation.

Organized by joint type (shoulders, legs, feet), each servo group is tested
with slow sweeps from rest to min, min to max, and max to rest.

Usage: diagnostics.py
"""

import curses
import sys
import time
from typing import Dict, List, Tuple

from spotmicroai.configuration._config_provider import ConfigProvider, ServoName
from spotmicroai.constants import (
    POPUP_HEIGHT,
    POPUP_WIDTH,
    SWEEP_RATE_DEG_PER_FRAME,
    FRAME_DURATION,
)
from spotmicroai.hardware.servo import JointType
from spotmicroai.hardware.servo._servo import Servo
from spotmicroai.hardware.servo._servo_factory import ServoFactory
from spotmicroai.runtime.abort_controller.abort_controller import AbortController
from spotmicroai.spot_config.ui import theme as THEME, ui_utils
import spotmicroai.labels as LABELS


class DiagnosticsWizard:
    """Interactive wizard for servo diagnostics and symmetry testing."""

    def __init__(self, stdscr):
        """Initialize diagnostics wizard.

        Args:
            stdscr: The curses window object
        """
        self.stdscr = stdscr
        self.config_provider = ConfigProvider()
        self.servos: Dict[ServoName, Servo] = {}
        self.servo_groups: Dict[JointType, List[ServoName]] = {}
        self.popup_start_y = 0
        self.popup_start_x = 0

    def _load_all_servos(self) -> None:
        """Load all 12 servos and group by joint type."""
        for servo_name in ServoName:
            try:
                servo = ServoFactory.create(servo_name)
                self.servos[servo_name] = servo

                joint_type = JointType.from_servo_name(servo_name)
                if joint_type not in self.servo_groups:
                    self.servo_groups[joint_type] = []
                self.servo_groups[joint_type].append(servo_name)
            except Exception as e:
                print(LABELS.DIAG_SERVO_ERROR.format(servo_name.value, e))
                raise

    def get_popup_position(self) -> Tuple[int, int]:
        """Calculate centered popup position."""
        h, w = self.stdscr.getmaxyx()
        start_y = max(1, (h - POPUP_HEIGHT) // 2)
        start_x = max(1, (w - POPUP_WIDTH) // 2)
        return start_y, start_x

    def create_popup_window(self) -> curses.window:
        """Create and configure a popup window."""
        self.popup_start_y, self.popup_start_x = self.get_popup_position()

        h, w = self.stdscr.getmaxyx()
        ui_utils.CursesUIHelper.draw_shadow(
            self.stdscr, self.popup_start_y, self.popup_start_x, POPUP_WIDTH, POPUP_HEIGHT, h, w
        )

        popup_win = curses.newwin(POPUP_HEIGHT, POPUP_WIDTH, self.popup_start_y, self.popup_start_x)
        popup_win.keypad(True)
        popup_win.bkgd(" ", curses.color_pair(THEME.REGULAR_ROW))
        return popup_win

    def refresh_popup_shadow(self) -> None:
        """Redraw the shadow after refreshing the popup window."""
        h, w = self.stdscr.getmaxyx()
        ui_utils.CursesUIHelper.draw_shadow(
            self.stdscr, self.popup_start_y, self.popup_start_x, POPUP_WIDTH, POPUP_HEIGHT, h, w
        )
        self.stdscr.refresh()

    def show_introduction(self) -> bool:
        """Show introduction screen with diagnostics instructions."""
        popup_win = self.create_popup_window()

        try:
            while True:
                popup_win.erase()
                popup_win.box()

                # Title
                title = LABELS.DIAG_TITLE
                title_x = max(1, (POPUP_WIDTH - len(title)) // 2)
                self._safe_addstr(popup_win, 1, title_x, title, curses.A_BOLD)

                try:
                    popup_win.hline(2, 1, curses.ACS_HLINE, POPUP_WIDTH - 2)
                except curses.error:
                    pass

                # Instructions
                instructions = [
                    LABELS.DIAG_INSTRUCTION,
                    "",
                    LABELS.DIAG_INTRO_LINE_1,
                    LABELS.DIAG_INTRO_LINE_2,
                    LABELS.DIAG_INTRO_LINE_3,
                    "",
                    LABELS.DIAG_INTRO_LINE_5,
                    LABELS.DIAG_INTRO_LINE_6,
                    LABELS.DIAG_INTRO_LINE_7,
                    LABELS.DIAG_INTRO_LINE_8,
                ]

                for i, line in enumerate(instructions):
                    self._safe_addstr(popup_win, 4 + i, 2, line)

                self._safe_addstr(popup_win, 13, 2, LABELS.DIAG_ENTER_BEGIN, curses.A_DIM)
                self._safe_addstr(popup_win, 14, 2, LABELS.DIAG_PRESS_ESC_CANCEL, curses.A_DIM)

                popup_win.refresh()
                self.refresh_popup_shadow()

                key = popup_win.getch()
                if key in (curses.KEY_ENTER, 10, 13):
                    return True
                elif key == 27:  # ESC
                    return False

        finally:
            curses.endwin()

    def _safe_addstr(self, win: curses.window, y: int, x: int, text: str, attr=0) -> None:
        """Safely add a string to the window, truncating if necessary."""
        try:
            h, w = win.getmaxyx()
            if y < 0 or y >= h or x < 0 or x >= w:
                return
            # Truncate text to fit within window width
            max_len = w - x - 1
            if max_len > 0:
                win.addstr(y, x, text[:max_len], attr)
        except curses.error:
            pass

    def sweep_servos(self, servo_names: List[ServoName], start_angle: float, end_angle: float) -> bool:
        """Sweep a group of servos from start_angle to end_angle.

        Args:
            servo_names: List of ServoName enums to sweep
            start_angle: Starting angle in degrees
            end_angle: Ending angle in degrees

        Returns:
            True if completed successfully, False if cancelled
        """
        popup_win = self.create_popup_window()

        try:
            # Clamp angles to valid ranges
            valid_start = start_angle
            valid_end = end_angle

            angle_diff = abs(valid_end - valid_start)
            if angle_diff == 0:
                return True

            direction = 1 if valid_end > valid_start else -1
            current_angle = valid_start
            start_time = time.time()
            progress_pct = 0.0

            while True:
                popup_win.erase()
                popup_win.box()

                # Title
                title = LABELS.DIAG_TITLE
                title_x = max(1, (POPUP_WIDTH - len(title)) // 2)
                self._safe_addstr(popup_win, 1, title_x, title, curses.A_BOLD)

                try:
                    popup_win.hline(2, 1, curses.ACS_HLINE, POPUP_WIDTH - 2)
                except curses.error:
                    pass

                # Show which servos are being tested
                servo_names_str = ", ".join(
                    [s.value.replace(LABELS.UNDERSCORE_CHAR, LABELS.SPACE_CHAR).title() for s in servo_names]
                )
                label_text = LABELS.DIAG_JOINT_TYPE_LABEL.format(servo_names_str[:50])
                self._safe_addstr(popup_win, 4, 2, label_text)

                progress_text = LABELS.DIAG_SWEEP_PROGRESS.format(valid_start, valid_end, progress_pct)
                self._safe_addstr(popup_win, 6, 2, progress_text)

                # Show current angles
                self._safe_addstr(popup_win, 8, 2, LABELS.DIAG_CURRENT_ANGLES)
                row = 9
                for servo_name in servo_names:
                    if row < 13:  # Limit to 4 servos displayed
                        servo = self.servos[servo_name]
                        display_name = servo_name.value.replace(LABELS.UNDERSCORE_CHAR, LABELS.SPACE_CHAR).title()
                        angle_text = LABELS.DIAG_SERVO_ANGLE_DISPLAY.format(display_name, current_angle)
                        self._safe_addstr(popup_win, row, 3, angle_text)
                        row += 1

                self._safe_addstr(popup_win, 13, 2, LABELS.DIAG_PRESS_ENTER_NEXT, curses.A_DIM)
                self._safe_addstr(popup_win, 14, 2, LABELS.DIAG_PRESS_ESC_CANCEL, curses.A_DIM)

                popup_win.refresh()
                self.refresh_popup_shadow()

                # Check for user input (non-blocking)
                popup_win.nodelay(True)
                key = popup_win.getch()
                popup_win.nodelay(False)

                if key == 27:  # ESC - cancel
                    return False

                # Calculate next angle based on sweep rate and time
                elapsed = time.time() - start_time
                total_steps = int(angle_diff / SWEEP_RATE_DEG_PER_FRAME) + 1
                step = min(int(elapsed / FRAME_DURATION), total_steps)
                current_angle = int(valid_start + direction * step * SWEEP_RATE_DEG_PER_FRAME)

                # Clamp to end angle
                if direction > 0:
                    current_angle = min(current_angle, valid_end)
                else:
                    current_angle = max(current_angle, valid_end)

                # Command all servos to this angle
                for servo_name in servo_names:
                    servo = self.servos[servo_name]
                    servo.angle = int(current_angle)

                # Check if we've reached the end
                reached_end = (direction > 0 and current_angle >= valid_end) or (
                    direction < 0 and current_angle <= valid_end
                )

                # Update progress percentage based on actual angle position (ensure it reaches 100% at end)
                if reached_end:
                    progress_pct = 100.0
                else:
                    if direction > 0:
                        progress_pct = ((current_angle - valid_start) / angle_diff) * 100 if angle_diff > 0 else 100
                    else:
                        progress_pct = ((valid_start - current_angle) / angle_diff) * 100 if angle_diff > 0 else 100

                if reached_end:
                    # Wait for user to press enter
                    while True:
                        key = popup_win.getch()
                        if key in (curses.KEY_ENTER, 10, 13):
                            return True
                        elif key == 27:
                            return False

                time.sleep(FRAME_DURATION)

        finally:
            curses.endwin()

    def test_joint_type(self, joint_type: JointType) -> bool:
        """Test all servos of a given joint type.

        Sequence:
        1. Move to rest position
        2. Sweep from rest to min
        3. Sweep from min to max
        4. Sweep from max to rest

        Args:
            joint_type: The JointType to test

        Returns:
            True if completed, False if cancelled
        """
        if joint_type not in self.servo_groups:
            return True

        servo_names = self.servo_groups[joint_type]
        if not servo_names:
            return True

        # Get angle limits for this joint type
        first_servo = self.servos[servo_names[0]]
        rest_angle = first_servo.rest_angle
        min_angle = first_servo.min_angle
        max_angle = first_servo.max_angle

        # Step 1: Move to rest position
        for servo_name in servo_names:
            self.servos[servo_name].angle = rest_angle

        # Step 2: Rest to Min
        if not self.sweep_servos(servo_names, rest_angle, min_angle):
            return False

        # Step 3: Min to Max
        if not self.sweep_servos(servo_names, min_angle, max_angle):
            return False

        # Step 4: Max to Rest
        if not self.sweep_servos(servo_names, max_angle, rest_angle):
            return False

        return True

    def show_completion(self) -> None:
        """Show completion screen."""
        popup_win = self.create_popup_window()

        try:
            while True:
                popup_win.erase()
                popup_win.box()

                title = LABELS.DIAG_TEST_COMPLETE
                title_x = max(1, (POPUP_WIDTH - len(title)) // 2)
                self._safe_addstr(popup_win, 1, title_x, title, curses.A_BOLD)

                try:
                    popup_win.hline(2, 1, curses.ACS_HLINE, POPUP_WIDTH - 2)
                except curses.error:
                    pass

                self._safe_addstr(popup_win, 5, 2, LABELS.DIAG_SUMMARY)
                self._safe_addstr(popup_win, 7, 2, LABELS.DIAG_SUCCESS_ALL_SERVOS)
                self._safe_addstr(popup_win, 8, 2, LABELS.DIAG_SUCCESS_NO_ERRORS)

                self._safe_addstr(popup_win, 13, 2, LABELS.DIAG_PRESS_ENTER_FINISH, curses.A_DIM)

                popup_win.refresh()
                self.refresh_popup_shadow()

                key = popup_win.getch()
                if key in (curses.KEY_ENTER, 10, 13):
                    return

        finally:
            curses.endwin()

    def run(self) -> bool:
        """Run the complete diagnostics wizard.

        Returns:
            True if completed successfully, False if cancelled
        """
        try:
            self._load_all_servos()

            if not self.show_introduction():
                return False

            # Test each joint type in order
            joint_type_order = [JointType.SHOULDER, JointType.LEG, JointType.FOOT]
            for joint_type in joint_type_order:
                if not self.test_joint_type(joint_type):
                    return False

            self.show_completion()
            return True

        except Exception as e:
            print(LABELS.DIAG_ERROR_GENERAL.format(e))
            return False


def main() -> None:
    """Main entry point for diagnostics."""
    abort_controller = AbortController()

    try:
        abort_controller.activate_servos()
        def diagnostics_wrapper(stdscr):
            curses.curs_set(0)
            curses.start_color()
            curses.use_default_colors()
            ui_utils.CursesUIHelper.init_colors(THEME.DEFAULT_THEME)
            stdscr.bkgd(" ", curses.color_pair(THEME.BACKGROUND))
            stdscr.refresh()

            wizard = DiagnosticsWizard(stdscr)
            return wizard.run()

        result = curses.wrapper(diagnostics_wrapper)

        if result:
            print(LABELS.DIAG_COMPLETED_SUCCESSFULLY)
        else:
            print(LABELS.DIAG_INTERRUPTED)

    except KeyboardInterrupt:
        print(LABELS.DIAG_INTERRUPTED)
        abort_controller.abort()
        sys.exit(1)
    except Exception as e:
        print(LABELS.DIAG_ERROR_GENERAL.format(e))
        abort_controller.abort()
        sys.exit(1)


if __name__ == "__main__":
    main()

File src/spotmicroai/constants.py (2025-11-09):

### Inverse Kinematics Constants ###
# Constants for inverse kinematics calculations (in mm)
LEG_LENGTH = 110
FOOT_LENGTH = 138
SHOULDER_LENGTH = 57
SAFE_NEUTRAL = (0.0, 0.0, 0.0)

### Motion Controller Constants ###
# Motion controller constants
# LEG_SERVO_OFFSET = 120
# FOOT_SERVO_OFFSET = 0
ROTATION_OFFSET = 40
INACTIVITY_TIME = 10

# Walking speed
MAX_WALKING_SPEED = 15

# Lean and height multipliers
LEAN_MULTIPLIER = 50
HEIGHT_MULTIPLIER = 40

# Rotation increment
ROTATION_INCREMENT = 0.025

# Buzzer
BEEP_DURATION = 0.5

# Debounce Button
DEFAULT_DEBOUNCE_TIME = 0.5

FRAME_RATE_HZ = 50
FRAME_DURATION = 1.0 / FRAME_RATE_HZ
TELEMETRY_UPDATE_INTERVAL = 2  # Update telemetry display every N frames

# Diagnostics Constants
SWEEP_RATE_DEG_PER_FRAME = 0.5  # Configurable sweep rate: degrees per frame (adjust for speed)

DEFAULT_SLEEP = 0.1


# Controller Constants
# ===============================
# General Timing and Publishing
# ===============================
# Rate (in Hz) at which the current joystick state is broadcast to the motion queue.
PUBLISH_RATE_HZ = 20.0
# Delay between read loop iterations (in seconds)
READ_LOOP_SLEEP = 0.01
# ===============================
# Analog Input Filtering
# ===============================
# Deadzone threshold for analog stick drift (0.0–1.0).
DEADZONE = 0.08
# Minimum absolute change in axis value required before updating state.
AXIS_UPDATE_THRESHOLD = 0.01
# Linux joystick drivers (via /dev/input/js*) report axis values as signed 16-bit integers
# The raw range is -32767 ... 32767
# -32767 means full movement in the negative direction (e.g., left or up),
# +32767 means full movement in the positive direction (e.g., right or down),
# 0 means centered.
# This vlaue is normalized to a float range of [-1.0, 1.0].
AXIS_NORMALIZATION_CONSTANT = 32767.0
DEVICE_PATH = '/dev/input'
JSIOCGNAME = 0x80006A13  # Joystick device name
JSIOCGAXES = 0x80016A11  # Number of joystick axes
JSIOCGBUTTONS = 0x80016A12  # Number of joystick buttons
JSIOCGAXMAP = 0x80406A32  # Joystick axis mapping
JSIOCGBTNMAP = 0x80406A34  # Joystick button mapping
# ===============================
# Reconnection and Device Search
# ===============================
# Delay between joystick access retries when device is not yet ready or permissions unavailable.
RECONNECT_RETRY_DELAY = 2.0
# Delay between failed device detection cycles.
DEVICE_SEARCH_INTERVAL = 1.0

# ===============================
# Calibration Wizard Constants
# ===============================
POPUP_HEIGHT = 16
POPUP_WIDTH = 75
CALIBRATION_STEP_SIZE = 10  # microseconds or degrees
# Offset in degrees for servo calibration due to geometry
GEOMETRY_OFFSET_SHOULDER = 0
GEOMETRY_OFFSET_LEG = 9.5
GEOMETRY_OFFSET_FOOT = 0

# ===============================
# Servo Validation Constants
# ===============================
SERVO_PULSE_WIDTH_MIN = 500  # microseconds
SERVO_PULSE_WIDTH_MAX = 2500  # microseconds

# ===============================
# Servo Manual Control Constants
# ===============================
ANGLE_STEP_SIZE = 1  # degrees per adjustment

# ===============================
# Remote Controller Constants
# ===============================
# Size of the joystick event buffer to read from /dev/input (in bytes)
JSDEV_READ_SIZE = 8

# ===============================
# LCD Display Constants
# ===============================
# Icon indices
ICON_EMPTY = 0
ICON_SUCCESS = 1
ICON_PCA9685 = 2
ICON_GPIO = 3
ICON_REMOTE_CONTROLLER = 4
ICON_TEMPERATURE = 5
ICON_PROBLEM = 6
ICON_SUCCESS_REVERSE = 7

# Icon bitmap data
# https://www.quinapalus.com/hd44780udg.html
CUSTOM_ICONS = {
    ICON_EMPTY: [0x0, 0x0, 0x0, 0x0, 0x0, 0x0, 0x0, 0x0],
    ICON_SUCCESS: [0x0, 0x1, 0x3, 0x16, 0x1C, 0x8, 0x0, 0x0],
    ICON_PCA9685: [0x1F, 0x11, 0x15, 0x15, 0x15, 0x15, 0x11, 0x1F],
    ICON_GPIO: [0x4, 0x4, 0x1F, 0x0, 0x0, 0xE, 0x4, 0x4],
    ICON_REMOTE_CONTROLLER: [0x11, 0xA, 0xE, 0xA, 0xA, 0xE, 0xA, 0x11],
    ICON_TEMPERATURE: [0x18, 0x18, 0x3, 0x4, 0x4, 0x4, 0x3, 0x0],
    ICON_PROBLEM: [0x0, 0x1B, 0xE, 0x4, 0xE, 0x1B, 0x0, 0x0],
    ICON_SUCCESS_REVERSE: [0x1F, 0x1E, 0x1C, 0x9, 0x3, 0x17, 0x1F],
}

# LCD cursor positions
LCD_CURSOR_BEING_LINE_1 = 0x80
LCD_CURSOR_BEGIN_LINE_2 = 0xC0

# LCD write mode for character output
LCD_DECIMAL_WRITE_MODE = 0b00000001

# ===============================
# Control Parameters
# ===============================
# Transition state filter time constant (seconds)
TRANSIT_TAU = 0.3
# Body motion rate limit (m/s) during transition state
TRANSIT_RL = 0.06
# Body motion angular rate limit (rad/s) during transition state
TRANSIT_ANGLE_RL = 0.35
# Maximum forward velocity (m/s)
MAX_FWD_VELOCITY = 0.4
# Maximum side velocity (m/s)
MAX_SIDE_VELOCITY = 0.4
# Maximum yaw rate (rad/s)
MAX_YAW_RATE = 0.35
# Loop time of main loop, seconds (0.02 s is 50 hz)
DT = 0.02
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

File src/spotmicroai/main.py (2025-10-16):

#!/usr/bin/env python3

import multiprocessing
import sys

from spotmicroai.abort_controller.abort_controller import AbortController
from spotmicroai.lcd_screen_controller.lcd_screen_controller import LCDScreenController
from spotmicroai.motion_controller.motion_controller import MotionController
from spotmicroai.remote_controller.remote_controller import RemoteControllerController
from spotmicroai.utilities.log import Logger

log = Logger().setup_logger()


def process_abort_controller(communication_queues):
    abort = AbortController(communication_queues)
    abort.do_process_events_from_queue()


def process_motion_controller(communication_queues):
    motion = MotionController(communication_queues)
    motion.do_process_events_from_queues()


def process_remote_controller_controller(communication_queues):
    remote_controller = RemoteControllerController(communication_queues)
    remote_controller.do_process_events_from_queues()


def process_output_lcd_screen_controller(communication_queues):
    lcd_screen = LCDScreenController(communication_queues)
    lcd_screen.do_process_events_from_queue()


def create_controllers_queues():
    communication_queues = {
        'abort_controller': multiprocessing.Queue(10),
        'motion_controller': multiprocessing.Queue(1),
        'lcd_screen_controller': multiprocessing.Queue(10),
    }

    log.info('Created the communication queues: %s', ", ".join(communication_queues.keys()))

    return communication_queues


def close_controllers_queues(communication_queues):
    log.info('Closing controller queues')

    for queue in communication_queues.items():
        queue.close()
        queue.join_thread()


def main():
    communication_queues = create_controllers_queues()

    # Abort controller
    # Controls the 0E port from PCA9685 to cut the power to the servos conveniently if needed.
    abort_controller = multiprocessing.Process(target=process_abort_controller, args=(communication_queues,))
    abort_controller.daemon = True  # The daemon dies if the parent process dies

    # Start the motion controller
    # Moves the servos
    motion_controller = multiprocessing.Process(target=process_motion_controller, args=(communication_queues,))
    motion_controller.daemon = True

    # Activate Bluetooth controller
    # Let you move the dog using the bluetooth paired device
    remote_controller_controller = multiprocessing.Process(
        target=process_remote_controller_controller, args=(communication_queues,)
    )
    remote_controller_controller.daemon = True

    # Screen
    # Show status of the components in the screen
    lcd_screen_controller = multiprocessing.Process(
        target=process_output_lcd_screen_controller, args=(communication_queues,)
    )
    lcd_screen_controller.daemon = True

    # Start the threads, queues messages are produced and consumed in those
    abort_controller.start()
    motion_controller.start()
    remote_controller_controller.start()
    lcd_screen_controller.start()

    if not abort_controller.is_alive():
        log.error("SpotMicro can't work without abort_controller")
        sys.exit(1)

    if not motion_controller.is_alive():
        log.error("SpotMicro can't work without motion_controller")
        sys.exit(1)

    if not remote_controller_controller:
        log.error("SpotMicro can't work without remote_controller_controller")
        sys.exit(1)

    # Make sure the thread/process ends
    abort_controller.join()
    motion_controller.join()
    remote_controller_controller.join()
    lcd_screen_controller.join()

    close_controllers_queues(communication_queues)


if __name__ == '__main__':
    log.info('Spotmicro starting...')

    try:
        main()

    except KeyboardInterrupt:
        log.info('Terminated due Control+C was pressed')

    else:
        log.info('Normal termination')

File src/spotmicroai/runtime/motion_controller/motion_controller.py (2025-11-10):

import math
import queue
import signal
import sys
import time

from spotmicroai import labels
import spotmicroai.constants as constants
from spotmicroai.hardware.servo.servo_service import ServoService
from spotmicroai.logger import Logger
from spotmicroai.runtime.controller_event import ControllerEvent
from spotmicroai.runtime.messaging import LcdMessage, MessageAbortCommand, MessageBus, MessageTopic, MessageTopicStatus
from spotmicroai.runtime.motion_controller.filtered_controller_event import FilteredControllerEvent
from spotmicroai.runtime.motion_controller.services import KeyframeService, PoseService, TelemetryService
from spotmicroai.singleton import Singleton

log = Logger().setup_logger('Motion controller')


class MotionController(metaclass=Singleton):
    """
    Controls the motion of the SpotMicro robot, handling servo movements, pose adjustments,
    and responding to controller inputs for walking, standing, and other actions.
    """

    _servo_service: ServoService
    _pose_service: PoseService
    _filtered_controller_event: FilteredControllerEvent

    _is_activated = False
    _is_running = False
    _keyframe_service: KeyframeService
    _telemetry_service: TelemetryService

    def __init__(self):
        """
        Initializes the MotionController with necessary services and queues.

        Args:
            communication_queues (dict): Dictionary of queues for inter-controller communication.
        """
        try:
            signal.signal(signal.SIGINT, self.exit_gracefully)
            signal.signal(signal.SIGTERM, self.exit_gracefully)

            self._servo_service = ServoService()
            self._pose_service = PoseService()
            self._keyframe_service = KeyframeService()
            self._filtered_controller_event = FilteredControllerEvent()

            # Initialize telemetry system
            self._telemetry_service = TelemetryService(self)

            self.prev_pitch_input: float | None = None
            self.prev_pitch_analog: float | None = None

            message_bus = MessageBus()
            self._motion_topic = message_bus.motion
            self._abort_topic = message_bus.abort
            self._lcd_topic = message_bus.lcd
            # self._telemetry_topic = message_bus.telemetry

            self._lcd_topic.put(LcdMessage(MessageTopic.MOTION, MessageTopicStatus.OK))

            time.sleep(constants.DEFAULT_SLEEP)

        except Exception as e:
            log.error(labels.MOTION_INIT_PROBLEM, e)
            self._lcd_topic.put(LcdMessage(MessageTopic.MOTION, MessageTopicStatus.OK))
            sys.exit(1)

    def exit_gracefully(self, _signum, _frame):
        """
        Handles graceful shutdown on signal reception, moving servos to rest and deactivating hardware.
        """
        log.info(labels.MOTION_GRACEFUL_SHUTDOWN)

        # Move servos to neutral (rest) first
        self._servo_service.rest_position()
        time.sleep(0.3)

        self._servo_service.deactivate_servos()

        self._abort_topic.put(MessageAbortCommand.ABORT)
        self._is_activated = False
        log.info(labels.MOTION_TERMINATED)
        sys.exit(0)

    def do_process_events_from_queues(self) -> None:
        """
        Main event processing loop that handles controller inputs, updates servo positions,
        manages activation states, and updates telemetry.
        """

        # State Variables
        inactivity_counter = time.time()

        raw_event: ControllerEvent | None = None
        self._filtered_controller_event = FilteredControllerEvent()

        # Telemetry variables
        cycle_index = None
        cycle_ratio = None
        leg_positions = None

        iteration_window_start = time.time()
        iteration_time_accumulator = 0.0
        iteration_samples = 0

        while True:
            frame_start = time.time()

            try:
                raw_event = self._motion_topic.get(block=False)
            except queue.Empty:
                raw_event = None

            # Filter the raw event through debouncing and smoothing
            if raw_event is not None:
                self._filtered_controller_event.update(raw_event)

            # Handle START button with debouncing
            if self._filtered_controller_event.start:
                inactivity_counter = self._handle_start_button_toggle(inactivity_counter)

            if not self._is_activated:
                time.sleep(0.1)
                continue

            # Get filtered event reference for cleaner code
            filtered_event = self._filtered_controller_event

            # Check if there's any user input activity
            has_input = filtered_event.has_activity()

            if not has_input:
                # if there is no user input, check to see if it have been long enough to warn the user
                if (time.time() - inactivity_counter) >= constants.INACTIVITY_TIME:
                    log.info(labels.MOTION_INACTIVITY_WARNING.format(constants.INACTIVITY_TIME))
                    log.info(labels.MOTION_SHUTDOWN_SERVOS)
                    log.info(labels.MOTION_PRESS_START_ENABLE)
                    self._deactivate()

                # throttle CPU when no input but still activated
                time.sleep(0.05)
                continue

            else:
                # If there activity, reset the timer
                inactivity_counter = time.time()

            try:
                if self._is_running:
                    # Update walking cycle and get current position
                    self._update_servo_angles()
                else:
                    # When not running, clear the telemetry values
                    cycle_index = None
                    cycle_ratio = None
                    leg_positions = None

                if filtered_event.a:
                    self._is_running = False
                    self._servo_service.rest_position()

                # Handle cases when robot is running
                if self._is_running:
                    # Right Trigger
                    # if filtered_event.right_trigger:
                    # Left Trigger
                    # if filtered_event.left_trigger:

                    if filtered_event.y:
                        pass

                    if filtered_event.b:
                        pass

                    if filtered_event.x:
                        pass

                    # D-Pad Left/Right
                    if filtered_event.dpad_horizontal != 0:
                        pass
                    # D-Pad Up/Down
                    if filtered_event.dpad_vertical != 0:
                        if filtered_event.dpad_vertical > 0:
                            self._keyframe_service.adjust_walking_speed(-1)
                        else:
                            self._keyframe_service.adjust_walking_speed(1)
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

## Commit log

2025-05-05 Add the 3D models
    [Base x 2.stl, Battery Cover.stl, Bearing End.stl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]
2025-10-05 Add 3D models and assembly instructions for robot components
    - Created README.md for 3D models detailing assembly parts and file paths.
    - Added STL files for various components including body, legs, shoulders, head, and covers.
    - Included images for each part to assist with assembly.
    - Documented optional parts and assembly notes for clarity.
    [base-x2.stl, battery-cover.stl, bearing-end.stl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]
2025-10-08 Refactor MotionController to implement frame rate control and adjust event processing timing
2025-10-08 Add deployment script and configuration file for SpotMicroAI
    - Implemented deploy.py to manage deployment configuration and SSH connection to Raspberry Pi.
    - Added functionality for user input, configuration loading/saving, and SSH connection testing.
    - Included various deployment actions such as initial setup, file syncing, and system updates.
    - Created spotmicroai.json configuration file to define hardware settings and behaviors for SpotMicroAI.
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2025-10-09 Add setup guides for Raspberry Pi: microSD preparation, SSH key configuration, and game controller pairing
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2025-10-09 Refactor motion controller configuration in config.py
    - Simplified motion controller PCA9685 settings by consolidating multiple entries into a single structure.
    - Updated servo configurations for rear and front limbs to follow a consistent format.
    - Removed redundant entries and streamlined the configuration for better readability and maintainability.
    - Fixed file path handling for saving configuration to ensure compatibility across different environments.
    [config.py, lcd_screen_controller.py, motion_controller.py]
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2025-10-10 Refactor motion controller and configuration management
    - Implemented Singleton pattern for PCA9685Board and General classes to ensure single instance usage.
    - Created ServoConfig and ServoConfigSet classes to manage servo configurations, including attributes for each servo.
    - Introduced ServoSet class to encapsulate all servos and their interactions.
    - Moved Singleton class definition to a separate singleton.py file for better organization and reusability.
    - Updated config.py to utilize the Singleton pattern for the Config class, removing redundant Singleton implementation.
    - Cleaned up imports and ensured proper usage of the Adafruit motor library for servo control.
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2025-10-12 Add motion controller services and related components
    - Implement KeyframeService for managing keyframes and walking cycles.
    - Create PoseService to handle predefined poses for the robot.
    - Introduce ServoConfigService for loading and managing servo configurations.
    - Develop ServoService to control the physical servos with staged angles.
    - Remove the obsolete WalkingCycle class.
    - Add Buzzer wrapper for controlling a buzzer via GPIO.
    - Implement PCA9685Board wrapper for managing PCA9685 servo controller.
    [buzzer.py, coordinate.py, motion_controller.py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]
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2025-10-14 feat: Rewrite setup tool for SpotmicroAI with automated first-time setup process
    - Implemented first-time setup detection and prerequisite checks
    - Simplified initial configuration prompts for hostname, username, and password
    - Added SSH key setup with options for existing or new keys
    - Automated setup process consisting of 8 steps including system update, I2C configuration, and Python package installation
    - Introduced status tracking to prevent re-running setup on already configured systems
    - Created detailed documentation including CHANGES.md, IMPLEMENTATION_SUMMARY.md, and README.md
    - Added error handling and user-friendly messages throughout the setup process
    [abort_controller.py, buzzer.py, calibration.py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]
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2025-10-15 fix: Update servo options order in calibration and test scripts for consistency
    [calibration.py]
2025-10-16 Refactor configuration management and improve code structure
    - Updated the configuration management to use DotDict for cleaner access to nested configurations.
    - Changed the way GPIO pins are accessed in various modules to use the new configuration structure.
    - Improved error handling and logging in the AbortController and Buzzer classes.
    - Refactored the ServoService to streamline servo initialization and angle management.
    - Enhanced beep utility to support command-line arguments and better GPIO cleanup.
    - Cleaned up imports and removed redundant code across multiple files.
    - Added type hints and improved code readability in several modules.
    - Fixed minor typos and inconsistencies in loggin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
    [abort_controller.py, buzzer.py, config.py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]
2025-10-16 fix: Update exit_gracefully method parameters to use underscore naming convention
    [abort_controller.py]
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2025-10-17 Refactor MotionController and related services for improved button management and servo control
    - Introduced ButtonManager to handle button debouncing and state management.
    - Updated MotionController to utilize ButtonManager for handling START and BACK button events.
    - Refactored KeyframeService to streamline keyframe transitions and calculations.
    - Enhanced ServoService with dedicated methods for setting servo angles for each leg.
    - Added debounced button functionality to prevent rapid re-triggers.
    - Improved PCA9685Board methods for activation and deactivation.
    - Updated Buzzer class to use configurable beep duration.
    - Added detailed docstrings for better code documentation and clarity.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
    [buzzer.py, constants.py, coordinate.py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]
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2025-10-19 fix: Update calibration script to correct directory paths and PYTHONPATH export
2025-10-19 fix: Simplify servo names retrieval in main menu and remove unnecessary global variable
    [calibration.py]
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2025-10-19 fix: Refactor servo creation for improved readability and maintainability
    [servo_service.py]
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2025-10-20 fix: Update servo parameters and constants for improved motion control
    [constants.py, coordinate.py]
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2025-10-20 fix: Update servo parameters for improved motion control and logging enhancements in remote controller test
2025-10-20 fix: Standardize variable naming for joystick device handling in remote controller test
2025-10-21 Major repository restructuring
    [calibrate_servos.json]
2025-10-21 feat: Implement numerical shortcuts and scrolling for enhanced menu navigation
    [calibrate_servos.json]
2025-10-21 Add menu system and localization for SpotMicroAI setup tool
    - Introduced a curses-based menu system in `menu_app.py` to handle user interactions.
    - Created a centralized localization module `labels.py` for user-facing strings.
    - Implemented JSON-driven menu definitions for various functionalities including calibration, configuration editing, diagnostics, log review, and runtime upload.
    - Added base menu launcher class to streamline submenu execution.
    - Developed theme definitions for consistent UI styling across the application.
    - Ensured proper error handling and user feedback throughout the menu interactions.
    [calibrate_servos.json]
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2025-10-21 Move the setup_app to the src folder
    [calibrate_servos.json]
2025-10-21 fix: Correct import statement for MenuApp in main.py
    [main.py]
2025-10-23 Perform major restructuring of the code base
    [calibrate_servos.json]
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2025-10-23 Refactor servo calibration process and menu integration
    - Introduced a new interactive servo calibration script (calibrate_servo.py) to handle individual servo adjustments for minimum pulse, maximum pulse, rest angle, and range.
    - Updated the servo driver to expose the PWM channel for direct control.
    - Created a new menu structure for servo calibration in JSON format, allowing for nested submenu navigation.
    - Removed the old calibration script (calibration.py) and replaced it with a more modular approach.
    - Updated the main menu to link to the new servo calibration menu.
    - Added a shell script (calibrate_servo.sh) to facilitate the execution of the new calibration script within a virtual env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
    [calibrate_servo.json, calibrate_servos.json]
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2025-10-23 feat: Add servo calibration modes menu and update references in calibration scripts
    [calibrate_servo_modes.json, calibrate_servos.json]
2025-10-23 feat: Implement servo calibration wizard and manual control scripts
    [calibrate_servo_modes.json]
2025-10-24 feat: Add servo calibration menus and update calibration wizard to support all servos
    [calibrate_servo_advanced_select.json, calibrate_servo_manual_select.json, calibrate_servo_select_mode.json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]
2025-10-24 feat: Remove obsolete servo calibration menus and add configuration editor
    [calibrate_servo_modes.json, calibrate_servos.json]
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2025-10-25 Add calibration wizard and manual control for servos
    - Implemented `calibration_wizard.py` for interactive servo calibration, allowing users to calibrate individual servos or all servos sequentially.
    - Created `calibration_wizard.sh` script to facilitate running the calibration wizard from the command line.
    - Developed `servo_controller.py` to manage servo hardware control during calibration, including pulse width and angle adjustments.
    - Added `servo_manual_control.py` for real-time manual servo movement, enabling users to test servo range and motion.
    - Introduced `servo_manual_control.sh` script for executing manual control from the command line.
    - Updated JSON menu configurations to point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
    [calibrate_servo.json, calibrate_servo_manual_select.json, calibrate_servo_wizard_select.json]
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2025-10-25 feat: Remove interactive servo calibration scripts and associated menu configurations
    [calibrate_servo.json, calibrate_servo_advanced_select.json, calibrate_servo_select_mode.json]
2025-10-25 feat: Update servo calibration menu structure and remove obsolete selection mode
    [calibrate_servo_select_mode.json]
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2025-10-26 fix: Update physical angles in calibration specs to remove decimal points
2025-10-28 Refactor servo configuration and initialization
    - Removed unused attributes (rest_angle, range) from ServoConfig and updated related code.
    - Simplified ConfigProvider methods for getting and setting servo configurations.
    - Updated spotmicroai.template to reflect changes in servo configuration structure.
    - Introduced AngleLimits and JointType to manage servo angle limits and types.
    - Enhanced Servo class to support angle limits and recalibration.
    - Implemented ServoFactory for creating servo instances with validation.
    - Removed deprecated spotmicroai.json configuration file.
    - Updated ServoService to utilize the new ServoFactory for servo initialization.
    - Added error handling for invalid ser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
    [_angle_limits.py, _config_provider.py, _joint_type.py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]
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2025-10-28 fix: Improve angle calculation for inverted servos in Servo class
    [_servo.py]
2025-10-28 fix: Correct servo inversion handling and pulse adjustments in calibration controls
    [_servo.py, calibration_wizard.py]
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2025-10-28 fix: Correct import statement for GPIO in buzzer handler
    [buzzer.py]
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2025-10-28 feat: Implement buzzer module for audio feedback control
    [buzzer.py, motion_controller.py]
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2025-10-29 Add final inverse kinematics formulas and remove outdated documents
    - Introduced a new document `IK-Final-Formulas.md` containing the final mathematical formulas for SpotMicro's inverse kinematics, including detailed system parameters, joint angle conventions, and step-by-step calculations.
    - Deleted obsolete documents: `IK-GPT5.md`, `IK-Gemeni-offset-corrected.md`, `IK-Gemeni-simple.md`, and `inverse-kinematics.md` to streamline the documentation and avoid redundancy.
    - Updated the Python script `spotmicro_ik.py` to implement the final inverse kinematics calculations, ensuring it reflects the latest formulas and conventions.
    - Improved error handling and output formatting in the Python scri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
2025-10-30 restructure the manu app and flatten the module
    [calibrate_servo_manual_select.json, calibrate_servo_wizard_select.json]
2025-10-31 fix: Correct duty cycle calculation to ensure integer value for PWM channel
    [_servo.py]
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2025-10-31 Refactor configuration application and menus for SpotMicroAI
    - Updated the launch command in connect_tool.py to use spot_config.sh instead of config_app.sh.
    - Changed the service execution script in spotmicroai.service from run.sh to runtime.sh.
    - Added a new runtime.sh script to manage the SpotMicroAI runtime with PID locking and virtual environment activation.
    - Removed debug print statement from motion_controller.py.
    - Enhanced servo initialization in _servo.py to include channel index.
    - Adjusted servo factory validation logic in _servo_factory.py for pulse width checks.
    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
    [calibrate_servo_manual_select.json, calibrate_servo_wizard_select.json]
2025-10-31 feat: Add servo calibration system with interactive wizard and configuration files
    [calibrate_servo_manual_select.json, calibrate_servo_wizard_select.json]
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2025-11-01 fix: Update leg and foot delta calculations to use angle ranges for incremental motion
    [motion_controller.py]
2025-11-01 feat: Add buzzer and LCD display modules with initialization and control logic refactor: Organize servo-related modules under hardware directory fix: Update imports for buzzer, LCD display, and servo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
    [_angle_limits.py, _joint_type.py, _servo.py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]
2025-11-01 fix: Add 'smbus' to ignored modules in pylint configuration
    [buzzer.py]
2025-11-01 fix: Remove unnecessary call to clear_staged() in commit method
    [servo_service.py]
2025-11-01 fix: Adjust servo angle ranges to be symmetric for smoother motion control
    [motion_controller.py]
2025-11-02 Refactor SpotMicroAI: Implement Gait Controller and Inverse Kinematics
    - Removed the legacy inverse kinematics script `spotmicro_ik_test.py`.
    - Introduced `ServoService` for managing servo operations, encapsulating all servo-related functionalities.
    - Created a new `GaitController` to handle walking mechanics, processing velocity commands and stepping the gait at a fixed frequency.
    - Added `GaitService` to compute walking gaits and foot positions based on commanded body velocity.
    - Implemented `InverseKinematicsSolver` for calculating joint angles based on target foot positions, considering physical offsets.
    - Established data models for the gait controller, including `BodyState`, `SpotMicro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
    [main.py, motion_controller.py, servo_service.py]
2025-11-03 fix: Update GPIO import statement for compatibility with RPi.GPIO
    [_config_provider.py, abort_controller.py]
2025-11-03 fix: Update servo pulse ranges for improved control and consistency
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2025-11-04 feat: Integrate Buzzer functionality into ServoService for activation and deactivation feedback
    [motion_controller.py, servo_service.py]
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2025-11-05 fix: Update SystemParameters initialization and improve docstring clarity
    [_system_parameters.py]
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2025-11-10 fix: Update default parameters for FilteredAnalogAxis and implement adaptive smoothing method
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
